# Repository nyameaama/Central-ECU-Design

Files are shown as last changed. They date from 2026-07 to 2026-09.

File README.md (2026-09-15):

# Central ECU

This is the engine-side ECU for the [Converse Engine](https://github.com/nyameaama/Converse-Engine). The engine is packaged as a thruster, so I am keeping everything on this side as small as I can.

Tank isolation, pressurization, regulation, relief, venting, filling, draining, bulk filtration, and service plumbing are all on the tank side. The thruster gets propane, N2O, regulated GN2, 28 V power, and CAN. The Central ECU runs the local firing sequence, drives the six engine valves and spark igniter, reads the engine sensors, and reports back to the vehicle over CAN.

## First design P&ID

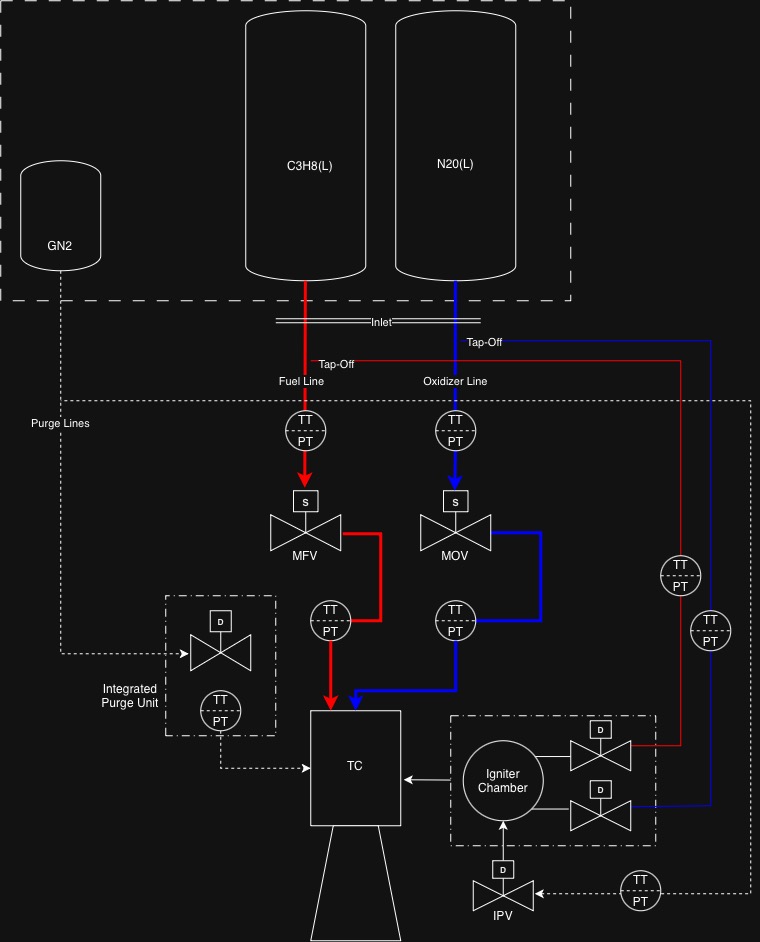
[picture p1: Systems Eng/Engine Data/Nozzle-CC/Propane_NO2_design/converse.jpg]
First design P&ID


This is the first design I am locking down. MFV and MOV are the main engine shutoff valves. IFV and IOV tap off upstream of them so the torch can light before the main valves open. The igniter fuel and oxidizer PT/TT pickups are downstream of IFV and IOV.

The GN2 arriving at the thruster is already regulated. CPV handles the main chamber purge and IPV handles the torch chamber purge. All six fluid valves are normally closed.

## Engine

| Engine | Section view |
| --- | --- |
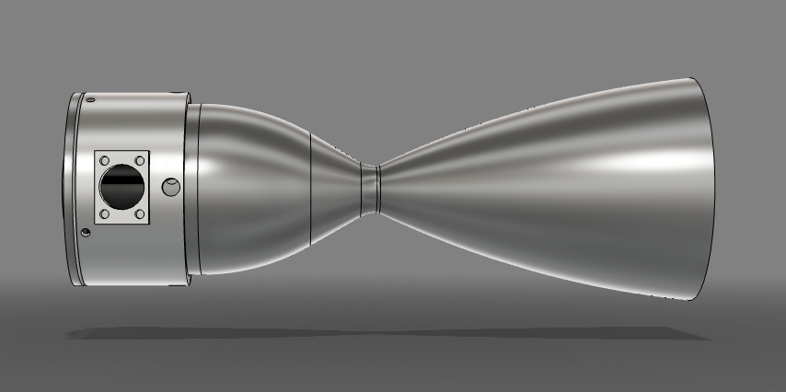
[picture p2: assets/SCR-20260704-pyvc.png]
Converse Engine exterior
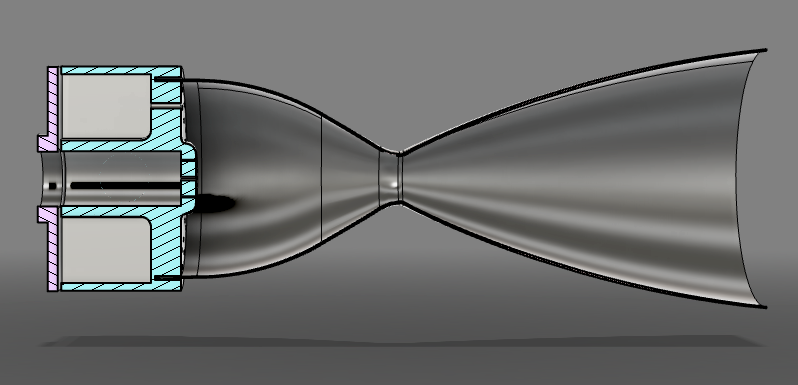
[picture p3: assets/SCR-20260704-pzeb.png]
Converse Engine section
|  |  |

## Current enclosure

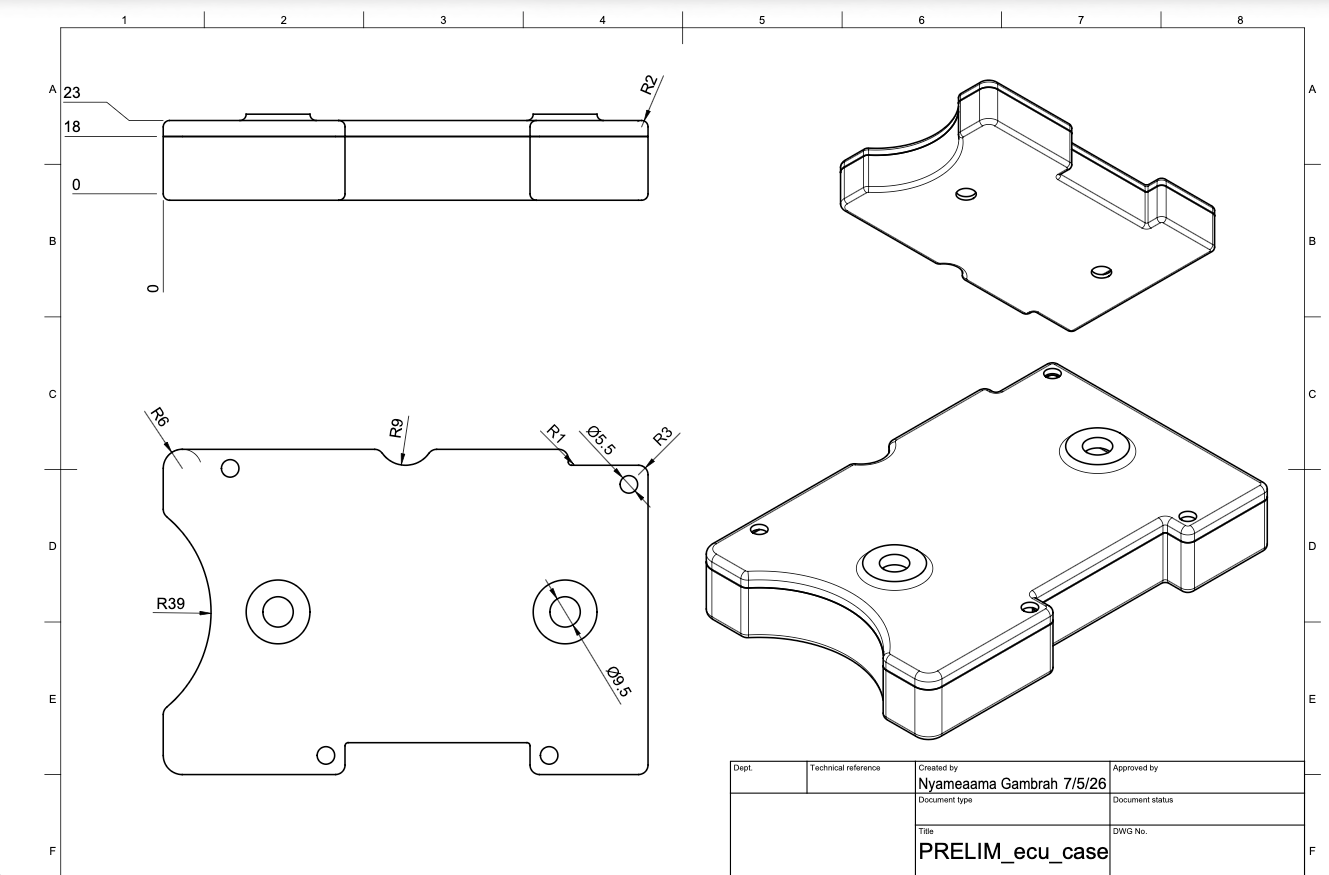
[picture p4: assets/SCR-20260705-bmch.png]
First ECU enclosure


This is the first enclosure pass. I am using it to get a real PCB outline and connector layout.

- 18 mm main body height
- 23 mm max height
- R2 top edge
- R39 PCB keepout
- R6 outer corners with the smaller R9, R7, and R3 transitions from the CAD
- two 9.5 mm engine mounting holes
- 5.5 mm PCB mounting holes
- separate battery clamp with covered terminals and service access
- sealed lid and connector openings

## Power

- 28 V nominal aircraft bus
- regulated 24 V valve rail
- 12 V ignition and sensor rails
- 5 V analog and communications rail
- 3.3 V logic rail
- EnerSys CYCLON `0819-0020`, 12 V 2.5 Ah backup battery

The backup battery only keeps the controller, CAN, and sensor measurements alive. It does not run the valves or igniter. Loss of valve power closes every valve.

## Valves

| Tag | Function | First design part |
| --- | --- | --- |
| MFV | Main propane | Buschjost `2/918-69/0824/.272-GO-1E` |
| MOV | Main N2O | Buschjost `2/918-24/0824/.272-GO-1E` |
| IFV | Torch fuel | Valcor V19800 |
| IOV | Torch oxidizer | Valcor V19800 |
| CPV | Main chamber purge | Parker `20CC04EP7D7B` |
| IPV | Torch chamber purge | Parker `20CC04EP7D7B` |

I have seven identical `TPS26633PWPR` valve channels on the PCB. Six are assigned above and the seventh stays disabled as a spare. `SHDN` is the command for each normally closed valve. Every channel also returns current, fault status, power-good status, and output voltage.

The igniter uses two separate solenoid valves in this build.

## Measurements

I have eleven AST20PT mounting points:

- fuel before and after MFV
- N2O before and after MOV
- igniter fuel after IFV
- igniter oxidizer after IOV
- chamber purge after CPV
- igniter purge after IPV
- remote chamber pressure
- cooling jacket inlet and outlet

The line sensors give pressure and fluid temperature from the same port. Four chamber-wall thermocouples and one injector thermocouple handle the hot structure. ECU and valve-driver temperatures stay on the PCB.

## Firing sequence

The first sequence is:

1. Spark igniter on.
2. IFV and IOV open.
3. Torch pressure comes up.
4. MFV and MOV open.
5. Main chamber pressure comes up.
6. IFV and IOV close.
7. IPV opens and protects the torch during the main burn.
8. MFV and MOV close at shutdown.
9. CPV and IPV handle the post-fire purge.

The largest valve state is the four-valve ignition overlap with MFV, MOV, IFV, and IOV energized together.

## Safety and communications

- arm and safe
- abort and hardware inhibit
- valve power feedback
- igniter enable feedback
- service connector interlock
- CAN FD to the tank and vehicle controllers
- heartbeat and timeout handling
- fault reporting

The tank controller provides the upstream emergency isolation path if an engine valve fails open.

Parts, interfaces, and the power numbers are in [Systems Eng](Systems%20Eng/README.md).

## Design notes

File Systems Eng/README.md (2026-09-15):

# Systems Eng

These are my working numbers for the first thruster build. I am keeping the engine side lean and leaving tank isolation, pressurization, regulation, venting, filling, draining, and bulk filtration on the tank side.

The engine-side hardware is six normally closed valves, eleven AST20PT points, five thermocouples, the spark igniter, and the Central ECU. The PCB has seven valve channels, with six assigned and one spare.

- [First design P&ID](Engine%20Data/Nozzle-CC/Propane_NO2_design/converse.jpg)
- [Parts list](Procurement-BOM.md)
- [Power budget](Power-Budget.md)
- [Sensor interfaces](Sensor-Interface-Control.md)
- [Propellant line sizing](Propellant-Line-Sizing.md)
- [Propane/N2O engine files](Engine%20Data/Nozzle-CC/Propane_NO2_design/)
- [Datasheets](Datasheets/README.md)

The main [README](../README.md) is the short system summary.

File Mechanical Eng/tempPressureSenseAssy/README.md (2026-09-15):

# Temp and Pressure Sensor Assembly

This folder is only for the sensor mounting and cable-routing CAD on the thruster. The tank-side sensors and plumbing are outside this assembly.

My AST20PT locations are:

- fuel before and after MFV
- N2O before and after MOV
- igniter fuel after IFV
- igniter oxidizer after IOV
- chamber purge after CPV
- igniter purge after IPV
- remote chamber pressure pickup
- cooling jacket inlet and outlet

The hot-structure locations are four chamber-wall thermocouples and one injector thermocouple.

The igniter branch sensors sit after their valves. The chamber pressure sensor stays away from the hot wall on a remote pickup. PCB and electrical work stay in the EE project folders.

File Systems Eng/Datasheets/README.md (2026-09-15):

# Datasheets

| Part | File | Note |
| --- | --- | --- |
| TE AST20PT | [TE-AST20PT-Rev-D-2025.pdf](TE-AST20PT-Rev-D-2025.pdf) | Pressure and fluid temperature |
| Omega BLMI | [Omega-BLMI-Mineral-Insulated-Thermocouple.pdf](Omega-BLMI-Mineral-Insulated-Thermocouple.pdf) | Chamber and injector thermocouples |
| Omega PCC-SMP | [Omega-PCC-SMP-PCB-Connector.pdf](Omega-PCC-SMP-PCB-Connector.pdf) | Type K PCB connector |
| Omega SMPW | [Omega-SMPW-Thermocouple-Connector.pdf](Omega-SMPW-Thermocouple-Connector.pdf) | Type K cable connector |
| Phoenix 1681127 | [Phoenix-1681127-M12-Connector.pdf](Phoenix-1681127-M12-Connector.pdf) | AST20PT cable connector |
| MAX31856 | [Analog Devices datasheet](https://www.analog.com/media/en/technical-documentation/data-sheets/max31856.pdf) | Thermocouple interface |
| Buschjost 2/918 R272 | [Buschjost-2-918-R272-100bar.pdf](Buschjost-2-918-R272-100bar.pdf) | Main fuel and oxidizer valves |
| Buschjost 1E sensor | [Buschjost-Inductive-Position-Sensor.pdf](Buschjost-Inductive-Position-Sensor.pdf) | Main-valve position switch |
| Parker G7 | [Parker-G7-Series-Solenoid-Valves.pdf](Parker-G7-Series-Solenoid-Valves.pdf) | CPV and IPV regulated-GN2 purge valves |
| Valcor V19800 | [Valcor-V19800-Fuel-Shutoff-Valve.pdf](Valcor-V19800-Fuel-Shutoff-Valve.pdf) | IFV and IOV torch valves |
| TI TPS2663x | [TI-TPS2663x-eFuse.pdf](TI-TPS2663x-eFuse.pdf) | Per-valve eFuse and high-side switch |
| TDK-Lambda i7A | [TDK-Lambda-i7A-Specification.pdf](TDK-Lambda-i7A-Specification.pdf) | 28 V nominal bus to 24 V valve rail |
| EnerSys CYCLON 0819-0020 | [EnerSys-CYCLON-Selection-Guide.pdf](EnerSys-CYCLON-Selection-Guide.pdf) | Backup battery, 12 V 2x3 monobloc |

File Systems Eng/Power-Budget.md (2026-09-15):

# Power Budget

The vehicle feed is a 28 V nominal aircraft bus. The TDK-Lambda `I7A4W033A033V-003-R` makes the regulated 24 V valve rail. I have seven `TPS26633PWPR` valve channels on the PCB, with six assigned and one disabled spare.

The 24 V converter stays because the selected valve coils are 24 V parts. Raw 28 V is 16.7% above the nameplate voltage of the Buschjost coils.

## Valve loads

| Valve | Assignment | Nominal current | Channel budget current | Coil power |
| --- | --- | ---: | ---: | ---: |
| Buschjost fuel main | MFV | 1.83 A | 1.83 A | 44 W |
| Buschjost oxidizer main | MOV | 2.21 A | 2.21 A | 53 W |
| Valcor V19800, 30 ohm coil | IFV and IOV | not released at 24 V | 1.30 A | 31.2 W each at the budget current |
| Parker G7 | CPV and IPV | 0.42 A | 0.42 A | 10 W each |

MFV and MOV together draw 4.04 A and 97 W. The four-valve ignition overlap adds IFV and IOV and brings the valve rail to 6.64 A and 159.4 W. Normal main operation uses MFV, MOV, and IPV for 4.46 A and 107 W. CPV and IPV together use 0.83 A and 20 W during the full post-fire purge.

Valcor's sheet says 1.3 A at 30 V and 70 F for the 30 ohm coil. The stated current and resistance do not agree, so I carry the published 1.3 A as the worst case on the 24 V channel. The exact hot and cold current comes from the purchased dash number and valve test.

## Valve channels

| Channel | Assignment | `ILIM` resistor | Typical limit |
| ---: | --- | ---: | ---: |
| 1 | MFV | 7.15 kOhm | 2.52 A |
| 2 | MOV | 6.04 kOhm | 2.98 A |
| 3 | IFV | 11.3 kOhm | 1.59 A |
| 4 | IOV | 11.3 kOhm | 1.59 A |
| 5 | CPV | 24.0 kOhm | 0.75 A |
| 6 | IPV | 24.0 kOhm | 0.75 A |
| 7 | Spare | not loaded | disabled |

`SHDN` is the valve command. A 47 kOhm pull-down leaves every channel off while the controller is unpowered or resetting. `MODE` is open for latch-off after an overload. `IMON`, `FLT`, `PGOOD`, and output-voltage sensing return to the AM2634.

The `TPS26633PWPR` has a 31 mOhm typical internal FET. The two main channels dissipate about 0.26 W together including the eFuse operating current. The four-channel ignition state is about 0.49 W using the V19800 channel current. Each output has its own inductive clamp.

## Allowed valve states

| State | Energized valves |
| --- | --- |
| Safe | none |
| Torch light | IFV and IOV |
| Main ignition overlap | MFV, MOV, IFV, and IOV |
| Main run | MFV, MOV, and IPV |
| Post-fire purge | CPV and IPV |

CPV stays out of the ignition and main-run states. IPV stays out of the torch-light state and comes on after IFV and IOV close.

## Electronics loads

| Load | Power |
| --- | ---: |
| 11 AST20PT sensors | 1.32 W |
| AM2634 | 1.46 W |
| Analog supplies and rail monitoring | 5.00 W |
| CAN and service interface | 1.25 W |
| Eight MAX31856 parts | 0.053 W |
| Logic and small-load margin | 0.99 W |
| Two Buschjost position switches | 0.24 W max |
| Critical electronics total | 10.3 W |

The AM2634 number is the 1.460 W result from TI's traction-inverter estimate at 150 C junction. The AM263x supply is `TPS6538600QDCARQ1` plus a `TPS62903-Q1` 3 A core buck.

## Main-bus cases

| State | Input power | Current at 28 V | Equivalent current at 24 V | 25% margin at 24 V |
| --- | ---: | ---: | ---: | ---: |
| Safe, valves off | 12.1 W | 0.43 A | 0.51 A | 0.63 A |
| Post-fire purge, CPV and IPV | 33.2 W | 1.19 A | 1.38 A | 1.73 A |
| Main run, MFV, MOV, and IPV | 124.8 W | 4.46 A | 5.20 A | 6.50 A |
| Ignition overlap, four valves | 179.9 W | 6.43 A | 7.50 A | 9.37 A |

I use 95% efficiency for the 24 V valve conversion and 85% from the 12 V rail through the lower electronics rails. TDK's typical curve is around 97 to 98% near this operating point, so 95% is the number I keep in the budget.

The protected vehicle input is 10 A at 28 V, or 280 W before the igniter load. The released valve and electronics peak is about 180 W during ignition overlap. That leaves about 100 W before margin and about 55 W after applying the 25% system margin.

The i7A input range is 18 to 60 V and it requires the input to stay above the commanded output for regulation. Near a 24 V vehicle-bus minimum, the valve rail tracks below 24 V.

## Igniter

The spark igniter is custom. I have not found an off-the-shelf propane and N2O rocket igniter with a released part number, pressure interface, and input-current waveform for this engine.

Its peak current, pulse width, repetition rate, and maximum firing time are not in the total above yet. The first-design valve side is fixed as separate IFV and IOV solenoids.

## Backup

The controller, CAN, and measurement lines stay alive for 30 minutes after loss of the 28 V bus at ambient temperature down to -15 C. Backup does not power valves or ignition.

The critical electronics use 10.3 W. At 85% conversion efficiency, the battery supplies about 12.1 W or 1.01 A at 12 V. A 50% allowance for discharge rate, cold capacity, aging, state of charge, cutoff, and tolerance leaves 12.75 Wh at the electronics. That gives about 74 minutes by calculation, while my released number stays at 30 minutes.

The backup input is a 3 A path with a battery fuse, service disconnect, reverse-polarity protection, automatic switchover, battery current and voltage measurement, and low-voltage cutoff.

## Sources

- [Buschjost 2/918 R272](https://www.buschjostventile.de/en/products/2-918-08-R-272)
- [Buschjost position sensor](https://www.buschjostventile.de/api/attachments/93eacf07-07ba-4c1d-8806-5cbe40241766.pdf)
- [Parker G7](https://www.parker.com/content/dam/Parker-com/Literature/Fluid-Control-Division/Catalogs/Parker_FCD_Catalog-G7.pdf)
- [Valcor V19800](https://www.valcor.com/valcor-technical-datasheets/valcor_aircraft_V19800.pdf)
- [TI TPS2663](https://www.ti.com/product/TPS2663)
- [TI AM2634](https://www.ti.com/lit/ds/symlink/am2634-q1.pdf)
- [TI AM263x power estimator](https://www.ti.com/lit/an/sprad54/sprad54.pdf)
- [TI AM26x hardware guide](https://www.ti.com/lit/an/sprabjl/sprabjl.pdf)
- [TDK-Lambda i7A](https://product.tdk.com/en/system/files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)
- [EnerSys CYCLON](https://www.enersys.com/en-gb/products/batteries/cyclon/cyclon/)

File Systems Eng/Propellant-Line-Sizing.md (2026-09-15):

# Propellant Line Sizing

The source reports are in [Engine Data/Nozzle-CC/Propane_NO2_design](<Engine%20Data/Nozzle-CC/Propane_NO2_design/>). The [first design P&ID](Engine%20Data/Nozzle-CC/Propane_NO2_design/converse.jpg) is the layout I am carrying into the thruster.

The tank side hands the thruster propane, N2O, and regulated GN2. Tank isolation, pressurization, venting, draining, relief, and bulk filtration stay upstream of the thruster boundary. The engine side only carries the two main paths, the two torch tapoffs, CPV, and IPV.

## Main flow

| Stream | Mass flow | Density in this pass | Volume flow |
| --- | ---: | ---: | ---: |
| Propane | 0.39879 kg/s | 500 kg/m3 | 0.79758 L/s, 12.64 US gpm |
| N2O | 1.75468 kg/s | 750 kg/m3 | 2.33957 L/s, 37.08 US gpm |
| Total | 2.15347 kg/s | - | - |

The full-thrust O/F is 4.400. These mass flows come from `Converse-engine.txt`. The density values are first-pass numbers and stay tied to the actual tank outlet pressure and temperature.

## Bore check

I used:

`Q = mass flow / density`

`ID = sqrt(4 Q / (pi velocity))`

| Mean velocity | Propane ID | N2O ID |
| ---: | ---: | ---: |
| 3 m/s | 18.4 mm, 0.724 in | 31.5 mm, 1.241 in |
| 5 m/s | 14.3 mm, 0.561 in | 24.4 mm, 0.961 in |
| 7 m/s | 12.0 mm, 0.474 in | 20.6 mm, 0.812 in |
| 10 m/s | 10.1 mm, 0.397 in | 17.3 mm, 0.680 in |

The first mechanical interfaces are G1/2 to -8 on fuel and G3/4 to -12 on N2O. The Buschjost valves are local restrictions at DN10 fuel and DN20 oxidizer.

My first valve-drop estimates are:

- MFV: 9.5 psi
- MOV: 16.7 psi

The complete pressure-drop model includes the actual tube IDs, bends, adapters, valve curves, injector requirement, and the cooling-jacket loss if the fuel path uses the jacket. The N2O side also carries margin against flashing through the line and MOV.

## Torch branches

IFV and IOV tap off upstream of MFV and MOV. Their PT/TT points are downstream of the torch valves and upstream of the torch metering points.

The torch flow is a separate low-flow calculation from the main CEA mass flow. The first hardware layout keeps both torch valves independent and uses the downstream pressure and temperature readings with the final metering geometry.

## Purge branches

Regulated GN2 enters at one thruster interface and splits to CPV and IPV.

- CPV feeds the main chamber purge
- IPV feeds the torch chamber purge
- both purge PT/TT points are downstream of their valves
- IPV is on during the main burn after IFV and IOV close
- CPV is a post-fire function

Purge flow is set by the tank-side regulated pressure and the engine-side metering geometry. There are no engine-side propellant vent or manifold dump paths in this design.

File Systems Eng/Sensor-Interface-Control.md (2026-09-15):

# Sensor Interfaces

## AST20PT layout

I am fitting eleven AST20PT sensors for the first thruster build.

| ID | Location | Placement |
| --- | --- | --- |
| FP-IN | Main fuel inlet | Before MFV |
| FP-MAN | Fuel manifold | After MFV |
| OP-IN | Main N2O inlet | Before MOV |
| OP-MAN | N2O manifold | After MOV |
| FP-IGN | Igniter fuel | After IFV and before the torch metering point |
| OP-IGN | Igniter oxidizer | After IOV and before the torch metering point |
| PP-CH | Chamber purge | After CPV |
| PP-IGN | Igniter purge | After IPV |
| PC | Main chamber | Remote pressure pickup with a thermal standoff |
| CJ-IN | Cooling jacket inlet | Jacket inlet port |
| CJ-OUT | Cooling jacket outlet | Jacket outlet port |

The igniter branch sensors are downstream of IFV and IOV. They measure the pressure actually delivered toward the torch instead of repeating the main inlet readings.

Each AST20PT has four electrical connections:

| Signal | ECU connection |
| --- | --- |
| Sensor power | `SENS_12V` |
| Sensor return | `SENS_RTN` |
| Pressure | `P_OUT`, 1 to 5 V |
| Temperature | `T_OUT`, 1 to 5 V |

I carry 10 mA per sensor, or 110 mA and 1.32 W for all eleven. Both outputs have input protection, an RC filter, and scaling into the 3.3 V ADC range. The 1 to 5 V live range leaves room for open- and short-circuit detection.

The sensor-side plug is Phoenix `1681127`. It accepts 18 to 24 AWG wire and 4 to 6 mm cable. My harness baseline is four-core shielded PUR cable with the shield bonded at the ECU end.

The chamber sensor uses the same electrical interface. Its remote tube and restrictor trade temperature protection against pressure-response delay, so the installed response becomes part of the chamber-pressure calibration.

## Thermocouples

The hot-structure probe is Omega `BLMI-XL-K-116U-6-CC`. The cable plug is `SMPW-K-M` and the PCB socket is `PCC-SMP-K-5`.

I am using five channels:

- four chamber-wall points
- one injector point

The PCB keeps eight MAX31856 interfaces, leaving three spare channels. The Type K metal runs straight to the Type K PCB sockets and stays out of the copper AMPSEAL contacts.

Each MAX31856 uses 3.3 V, SPI clock and data, one chip select, and the datasheet input filter. `DRDY` and `FAULT` return to the controller where pins are available.

## Main sensor connectors

Two 35-way AMPSEAL headers give 70 cavities.

| Use | Cavities |
| --- | ---: |
| AST20PT pressure outputs | 11 |
| AST20PT temperature outputs | 11 |
| Sensor power feeds | 2 |
| Sensor returns | 2 |
| Spare | 44 |
| Total | 70 |

The two harness branches split sensor power and return. The thermocouples use their own Type K connectors.

## Main-valve position feedback

The Buschjost `1E` option is a three-wire PNP normally open inductive sensor. It runs from 10 to 30 VDC, draws less than 10 mA, and can source 100 mA.

Both position switches run from `SENS_12V`, which keeps closed-valve indication alive on backup power. A protected divider and Schmitt input bring each signal into the AM2634. My selected valve configuration reports the closed position.

## PCB notes

- AST20PT supply range is 10 to 28 V
- AST20PT sample rate is 400 Hz maximum
- sensor ground joins valve return at the power entry point
- the analog filter corner follows the selected sample rate
- ECU board temperature and valve-driver temperature are local PCB measurements

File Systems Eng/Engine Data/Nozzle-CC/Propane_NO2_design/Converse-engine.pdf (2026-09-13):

## Engine name: Converse

Mon Nov 29 20:46:48 2021

Propellant Specification
Component Temperature (K) Mass fraction Mole fraction
C3H8(L) | 231.08 | 0.19 | 0.18
N2O(L),298.15K | 298.15 | 0.81 | 0.82
| Total | 1.00 | 1.00
Exploded propellant formula:N1.630 O0.815 C0.555 H1.479
| O/F = 4.400
O/F⁰ = 9.981 (stoichiometric) αox = 0.441 (oxidizer excess coefficient)

Table 1. Thermodynamic properties

Parameter | Injector | Nozzle inlet | Nozzle throat | Nozzle exit | Unit
Pressure | 3.4474 | 3.4474 | 1.8973 | 0.0117 | MPa
Temperature | 2400.6726 | 2400.6726 | 2116.4505 | 823.2841 | K
Enthalpy | 666.6951 | 666.6951 | 129.7272 | -2476.5175 | kJ/kg
Entropy | 10.9970 | 10.9970 | 10.9970 | 10.9970 | kJ/(kg·K)
Internal energy | -290.2740 | -290.2740 | -713.5100 | -2790.7130 | kJ/kg
Specific heat (p=const) | 1.9405 | 1.9405 | 1.8640 | 10.3246 | kJ/(kg·K)
Specific heat (V=const) | 1.5351 | 1.5351 | 1.4634 | 8.7935 | kJ/(kg·K)
Gamma | 1.2641 | 1.2641 | 1.2738 | 1.1741
Isentropic exponent | 1.2636 | 1.2636 | 1.2736 | 1.1169
Gas constant | 0.3986 | 0.3986 | 0.3984 | 0.3816 | kJ/(kg·K)
Molecular weight (M) | 20.8579 | 20.8579 | 20.8686 | 21.7864
Molecular weight (MW) | 0.02086 | 0.02086 | 0.02087 | 0.02124
Density | 3.6024 | 3.6024 | 2.2500 | 0.0372 | kg/m³
Sonic velocity | 1099.6349 | 1099.6349 | 1036.3089 | 592.3949 | m/s
Velocity | 0.0000 | 0.0000 | 1036.3089 | 2507.2745 | m/s
Mach number | 0.0000 | 0.0000 | 1.0000 | 4.2324
Area ratio | infinity | infinity | 1.0000 | 25.0000
Mass flux | 0.0000 | 0.0000 | 2331.7360 | 93.2322 | kg/(m²·s)
Mass flux (relative) | 0.000e-04 | 0.000e-04 | | | kg/(N·s)
Viscosity | 7.56e-05 | 7.56e-05 | 6.929e-05 | 3.673e-05 | kg/(m·s)
Conductivity, frozen | 0.2451 | 0.2451 | 0.2198 | 0.1049 | W/(m·K)
Specific heat (p=const), frozen | 1.852 | 1.852 | 1.822 | 1.581 | kJ/(kg·K)
Prandtl number, frozen | 0.5711 | 0.5711 | 0.5744 | 0.5533
Conductivity, effective | 0.2826 | 0.2826 | 0.2332 | nan | W/(m·K)
Specific heat (p=const), effective | 1.941 | 1.941 | 1.864 | 1.581 | kJ/(kg·K)
Prandtl number, effective | 0.5191 | 0.5191 | 0.5539 | nan

Table 2. Fractions of the combustion products

Species | Injector Injector Nozzle inlet Nozzle inlet mass | mole
mass | mole fractions | fractions fractions
fractions

Nozzle Nozzle Nozzle exit Nozzle exit throat throat mass mole
mass | mole | fractions | fractions
| | | | | fractions | fractions
C(gr) | | | | | | | 0.0141885 0.0250908
CH4 | 0.0000002 | 0.0000002 | 0.0000002 | 0.0000002 | 0.0000002 | 0.0000003 | 0.0066388 0.0087896
CO | 0.3288592 | 0.2448866 | 0.3288592 | 0.2448866 | 0.3256783 | 0.2426427 | 0.1754557 0.1330459
CO2 | 0.0377299 | 0.0178817 | 0.0377299 | 0.0178817 | 0.0427448 | 0.0202689 | 0.2085925 0.1006702
1
Species | Injector mass fractions
Injector Nozzle inlet Nozzle inlet | Nozzle
| | | | | throat mass fractions | | Nozzle Nozzle exit Nozzle exit
| | mole fractions | mass fractions | mole fractions | | throat mole fractions
mass | mole
fractions | fractions
COOH | 0.0000003 | 0.0000001 | 0.0000003 | 0.0000001
H | 0.0000650 | 0.0013455 | 0.0000650 | 0.0013455 | 0.0000190 | 0.0003941
H2 | 0.0236045 | 0.2442308 | 0.0236045 | 0.2442308 | 0.0238767 | 0.2471740 | 0.0266082 0.2803491
H2O | 0.0910036 | 0.1053628 | 0.0910036 | 0.1053628 | 0.0890350 | 0.1031366 | 0.0498966 0.0588273
HCHO,formaldehy | 0.0000012 | 0.0000008 | 0.0000012 | 0.0000008 | 0.0000007 | 0.0000005
HCN | 0.0000148 | 0.0000114 | 0.0000148 | 0.0000114 | 0.0000085 | 0.0000066
HCO | 0.0000026 | 0.0000019 | 0.0000026 | 0.0000019 | 0.0000007 | 0.0000005
HCOOH | 0.0000007 | 0.0000003 | 0.0000007 | 0.0000003 | 0.0000004 | 0.0000002
HNC | 0.0000014 | 0.0000011 | 0.0000014 | 0.0000011 | 0.0000005 | 0.0000004
HNCO | 0.0000029 | 0.0000014 | 0.0000029 | 0.0000014 | 0.0000016 | 0.0000008
N2 | 0.5185805 | 0.3861180 | 0.5185805 | 0.3861180 | 0.5185934 | 0.3863262 | 0.5185982 0.3932003
NH2 | 0.0000005 | 0.0000007 | 0.0000005 | 0.0000007 | 0.0000001 | 0.0000001
NH3 | 0.0000246 | 0.0000302 | 0.0000246 | 0.0000302 | 0.0000199 | 0.0000244 | 0.0000213 0.0000266
NO | 0.0000111 | 0.0000077 | 0.0000111 | 0.0000077 | 0.0000014 | 0.0000010
O | 0.0000003 | 0.0000004 | 0.0000003 | 0.0000004
OH | 0.0000963 | 0.0001181 | 0.0000963 | 0.0001181 | 0.0000184 | 0.0000226

Table 3. Theoretical (ideal) performance
Parameter | Sea level | Sea level (flow sep.) | Optimum expansion | Vacuum | Unit
Characteristic velocity | | | 1478.46 | | m/s
Effective exhaust velocity | 1545.78 | 1768.87 | 2507.27 | 2632.59 | m/s
Specific impulse (by mass) | 1545.78 | 1768.87 | 2507.27 | 2632.59 | N·s/kg
Specific impulse (by weight) | 157.63 | 180.37 | 255.67 | 268.45 | s
Thrust coefficient | 1.0455

Table 4. Estimated delivered performance

1.1964 | 1.6959 | 1.7806
Parameter | Sea level | Sea level (flow sep.) | Optimum expansion | Vacuum | Unit
Characteristic velocity | | | 1438.85 | | m/s
Effective exhaust velocity | 1417.46 | 1643.14 | 2378.95 | 2504.26 | m/s
Specific impulse (by mass) | 1417.46 | 1643.14 | 2378.95 | 2504.26 | N·s/kg

Specific impulse (by weight) | 144.54 | 167.55 | 242.59 | 255.36

s
Thrust coefficient | 0.9851 | 1.1420 | 1.6534 | 1.7405
Ambient condition for optimum expansion: H=15.23 km, p=0.115 atm
2

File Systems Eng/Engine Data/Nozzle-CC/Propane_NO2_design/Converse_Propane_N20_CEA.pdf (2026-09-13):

NASA-GLENN CHEMICAL EQUILIBRIUM PROGRAM CEA2, FEBRUARY 5, 2004 BY BONNIE MCBRIDE AND SANFORD GORDON REFS: NASA RP-1311, PART I, 1994 AND NASA RP-1311, PART II, 1996

*******************************************************************************

### CEA analysis performed on Tue 14-Dec-2021 15:02:54

# Problem Type: "Rocket" (Infinite Area Combustor)

prob case=Converse_______2705 ro equilibrium

# Pressure (1 value):

p,psia= 750
# Chamber/Exit Pressure Ratio (1 value): pi/p= 51.02

# Oxidizer/Fuel Wt. ratio (1 value):

o/f= 4.4

# You selected the following fuels and oxidizers: reac

fuel C3H8(L) | wt%=100.0000
oxid N2O | wt%=100.0000

# You selected these options for output:

# short version of output

output short
# Proportions of any products will be expressed as Mass Fractions. output massf

# Heat will be expressed as siunits

output siunits

# Input prepared by this script:/var/www/sites/cearun.grc.nasa.gov/cgi-bin/CEARU N/prepareInputFile.cgi

### IMPORTANT: The following line is the end of your CEA input file!

end

THEORETICAL ROCKET PERFORMANCE ASSUMING EQUILIBRIUM

COMPOSITION DURING EXPANSION FROM INFINITE AREA COMBUSTOR

Pin = 750.0 PSIA
CASE = Converse_______
REACTANT | WT FRACTION | ENERGY | TEMP
(SEE NOTE) | KJ/KG-MOL | K
FUEL | C3H8(L) | 1.0000000 | -128228.000 | 231.076
OXIDANT | N2O | 1.0000000 | 0.000 | 0.000
O/F= | 4.40000 | %FUEL= 18.518519 | R,EQ.RATIO= 2.268459 | PHI,EQ.RATIO= 2.268459
CHAMBER | THROAT | EXIT
Pinf/P | 1.0000 | 1.8248 | 51.020
P, BAR | 51.710 | 28.338 | 1.0135
T, K | 1751.69 | 1532.82 | 906.28
RHO, KG/CU M | 7.4122 0 4.6426 0 2.9816-1
H, KJ/KG | -538.51 | -931.32 -2414.33
U, KJ/KG | -1236.15 -1541.71 -2754.26
G, KJ/KG | -18495.7 -16644.7 -11704.9
S, KJ/(KG)(K) | 10.2513 | 10.2513 | 10.2513
M, (1/n) | 20.877 | 20.880 | 22.167
MW, MOL WT | 20.877 | 20.880 | 21.655
(dLV/dLP)t | -1.00030 -1.00056 -1.05903
(dLV/dLT)p | 1.0018 | 1.0045 | 2.0623
Cp, KJ/(KG)(K) | 1.8066 | 1.7967 | 9.2320
GAMMAs | 1.2836 | 1.2871 | 1.1284
SON VEL,M/SEC | 946.3 | 886.4 | 619.3
MACH NUMBER | 0.000 | 1.000 | 3.127

PERFORMANCE PARAMETERS

Ae/At | 1.0000 | 7.1255
CSTAR, M/SEC | 1256.6 | 1256.6
CF | 0.7054 | 1.5414
Ivac, M/SEC | 1575.0 | 2112.4
Isp, M/SEC | 886.4 | 1936.9

MASS FRACTIONS

CH4 | 0.00003 | 0.00008 | 0.01386
*CO | 0.31866 | 0.31151 | 0.17791
*CO2 | 0.05367 | 0.06478 | 0.18999
HCN | 0.00003 | 0.00002 | 0.00000
*H2 | 0.02437 | 0.02486 | 0.02326
H2O | 0.08463 | 0.08013 | 0.06355
NH3 | 0.00011 | 0.00011 | 0.00007
*N2 | 0.51851 | 0.51852 | 0.51855
C(gr) | 0.00000 | 0.00000 | 0.01280

* THERMODYNAMIC PROPERTIES FITTED TO 20000.K

NOTE. WEIGHT FRACTION OF FUEL IN TOTAL FUELS AND OF OXIDANT IN TOTAL OXIDANTS

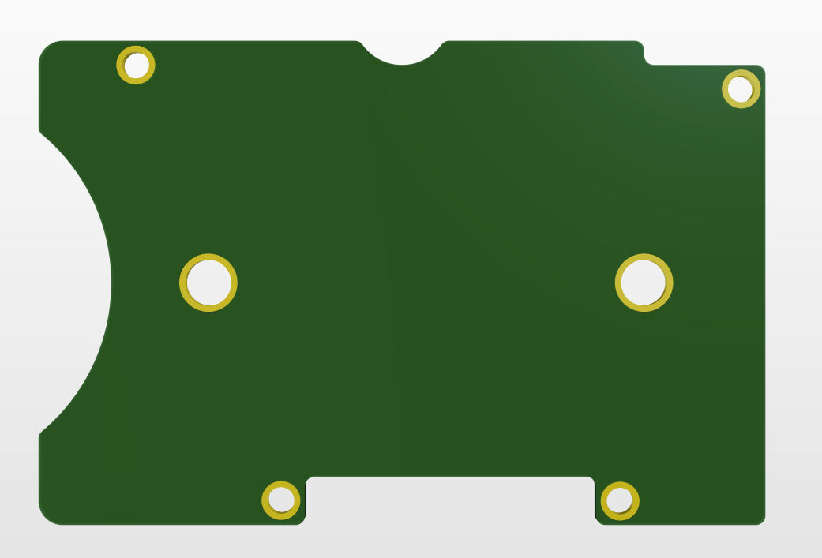
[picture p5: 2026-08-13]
assets/SCR-20260705-bvih.png

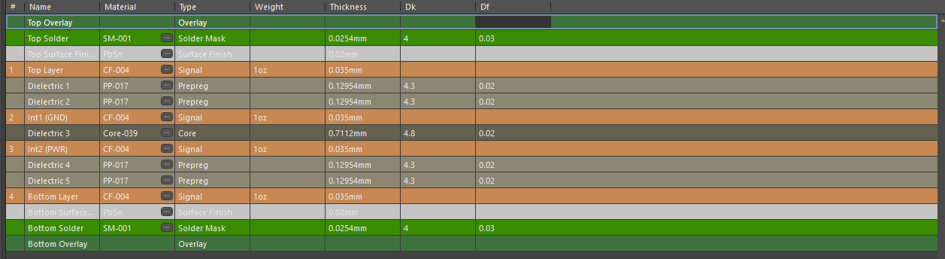
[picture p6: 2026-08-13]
assets/SCR-20260705-bvmq.png

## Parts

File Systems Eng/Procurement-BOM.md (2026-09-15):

# Parts List

This is the first-build list for the six-valve thruster. My last general stock check was 2026-08-01. I checked the TPS26633, i7A, and Parker G7 again on 2026-08-28.

## Sensors

| Buy | Fitted | Part | Where I am using it |
| ---: | ---: | --- | --- |
| 12 | 11 | TE `AST20PT4A01500P3Y1H000` | Main lines, igniter branches, both purge branches, remote chamber pickup, and cooling jacket |
| 12 | 11 | Phoenix `1681127` | Field-wireable M12 plug for each AST20PT |
| 5 | 5 | Omega `BLMI-XL-K-116U-6-CC` | Four chamber-wall points and one injector point |
| 5 | 5 | Omega `SMPW-K-M` | Type K cable plug |
| 1 pack | 5 | Omega `PCC-SMP-K-5` | Type K PCB sockets |
| 8 | 8 | Analog Devices `MAX31856MUD+T` | Five thermocouple channels and three spares |

The eleven AST20PT points are:

1. Fuel before MFV
2. Fuel after MFV
3. N2O before MOV
4. N2O after MOV
5. Igniter fuel after IFV
6. Igniter oxidizer after IOV
7. Chamber purge after CPV
8. Igniter purge after IPV
9. Remote chamber pressure
10. Cooling jacket inlet
11. Cooling jacket outlet

The selected AST20PT is 0 to 1500 psig with separate 1 to 5 V pressure and temperature outputs, an M12 connector, and a 1/4 inch MNPT process port. I am carrying one spare sensor and one spare M12 plug.

## ECU connectors

| Qty | Part | Use |
| ---: | --- | --- |
| 1 | TE `776231-1` | Black 35-way AMPSEAL PCB header |
| 1 | TE `776231-2` | Natural 35-way AMPSEAL PCB header |
| 1 | TE `776164-1` | Black mating plug |
| 1 | TE `776164-2` | Natural mating plug |
| 70 plus spares | TE `770520-3` | Gold socket contacts, 16 to 20 AWG |
| as needed | TE `770678-1` | Cavity plugs |

The two headers carry 22 AST20PT signal wires, two sensor-power feeds, two returns, and 44 spare cavities. The Type K connections stay separate from the AMPSEAL connectors.

## Valves

| Qty | Part | Assignment | What I am carrying |
| ---: | --- | --- | --- |
| 1 | Buschjost `2/918-69/0824/.272-GO-1E`, 24 VDC | MFV | NC direct coaxial valve, G1/2, DN10, Kv 2.5, 44 W |
| 1 | Buschjost `2/918-24/0824/.272-GO-1E`, 24 VDC | MOV | NC direct coaxial valve, G3/4, DN20, Kv 6.8, 53 W |
| 2 | Parker `20CC04EP7D7B`, 24 VDC | CPV and IPV | NC direct-acting G7 valve, 1/4 NPT, Cv 0.05, 10 W |
| 2 | Parker `ELECE5` | CPV and IPV | Six-foot DIN cord set |
| 2 | Valcor `V19800`, NC, 0.085 inch ESEO, 30 ohm continuous coil, top `MS3102A-10SL-4P` receptacle | IFV and IOV | First-design torch valves |
| 2 | Amphenol `MS3106A10SL-4S` | IFV and IOV | Cable plug for the Valcor receptacle |

The engine-side valve count stops at these six.

The main engine model calls for 0.39879 kg/s propane and 1.75468 kg/s N2O. My first density pass uses 0.50 kg/L propane and 0.75 kg/L N2O. That works out to 12.6 gpm fuel and 37.1 gpm oxidizer.

| | Fuel | Oxidizer |
| --- | ---: | ---: |
| Port and bore | G1/2, DN10 | G3/4, DN20 |
| Kv | 2.5 m3/h | 6.8 m3/h |
| Coil | 44 W | 53 W |
| Current at 24 V | 1.83 A | 2.21 A |
| Catalog switching time at 6 bar gas | 50 ms on, 80 ms off | 110 ms on, 100 ms off |
| First valve-drop estimate | 9.5 psi | 16.7 psi |

Both Buschjost configurations are normally closed, direct-electric 316 Ti stainless valves with PTFE/FKM seals. They are listed for 0 to 100 bar and continuous coil duty. `GO` is the cleaned version and `1E` adds one closed-position inductive sensor. The fuel side uses G1/2 to -8 and the oxidizer side uses G3/4 to -12.

The Buschjost resistance table lists the wetted materials as compatible with LPG and N2O. I still have the 100 bar feed limit, -10 C temperature floor, reverse-pressure limit, and actual `GO` cleaning certificate tied to the purchased configuration. The published switching times are gas tests, so my liquid timing comes from the assembled valve test.

The Parker G7 is only on regulated GN2. It is listed for zero to 2200 psi differential with air or inert gas, has a 3/64 inch orifice, and uses a 10 W coil. CPV feeds the main chamber purge and IPV feeds the torch chamber purge.

The V19800 setup is the 30 ohm continuous coil. Valcor's sheet also states 1.3 A at 30 V and 70 F, which does not agree with the listed 30 ohm resistance. I use the published 1.3 A as the per-channel worst case. The exact 24 V hot and cold current stays tied to the factory dash number and my valve bench data.

## ECU power parts

| Buy | Fitted | Part | Use |
| ---: | ---: | --- | --- |
| 1 | 1 | TDK-Lambda `I7A4W033A033V-003-R` | 28 V nominal bus to regulated 24 V valve rail |
| 8 | 7 | TI `TPS26633PWPR` | Six assigned valve channels and one disabled spare |
| 1 | 1 | TI `TPS6538600QDCARQ1` | AM2634 sequencing, watchdog, and supply supervision |
| 1 | 1 | TI `TPS62903-Q1` | 1.2 V AM2634 core supply |

The Buschjost coils stay on the regulated 24 V rail. I am not running the 24 V coils straight from the 28 V aircraft bus.

Every valve channel uses `SHDN` as the command and has a 47 kOhm pull-down. `IMON`, `FLT`, `PGOOD`, and output-voltage sensing return to the controller. The first current-limit values are:

| Valve channel | `ILIM` resistor | Typical limit |
| --- | ---: | ---: |
| MFV | 7.15 kOhm | 2.52 A |
| MOV | 6.04 kOhm | 2.98 A |
| CPV and IPV | 24.0 kOhm | 0.75 A |
| IFV and IOV | 11.3 kOhm | 1.59 A |

Each output has its own inductive clamp near the harness connector. The clamp voltage and release timing stay tied to the valve bench data because the coil inductance is not published.

## Backup battery

| Qty | Part | Use |
| ---: | --- | --- |
| 1 | EnerSys CYCLON `0819-0020` | 12 V, 2.5 Ah AGM backup battery |
| 1 | Power-Sonic `PSC-12500ACX` | Ground-service AGM charger |

The battery only carries the controller, CAN, and measurement electronics. It does not carry valves or ignition.

The battery is 113.8 x 89.4 x 70.4 mm, weighs 1.04 kg, and uses 0.187 inch Faston terminals. My enclosure has a separate clamp, covered terminals, a positive-terminal fuse, reverse-polarity protection, current measurement, automatic switchover, and low-voltage cutoff.

## Part status

- AST20PT is an active TE family. The selected configuration still goes through a TE or LADD quote.
- The Phoenix M12 plug, Omega connectors, MAX31856, TPS26633, TI power parts, i7A, and CYCLON battery are active parts.
- The two Buschjost main valves are made to order and have public STEP models.
- The Parker G7 is the released GN2 purge valve and has manufacturer CAD.
- The Valcor V19800 family is the released IFV/IOV choice for this pass. The factory dash number and fluid approval come back with the quote.

## Links

- [AST20PT](https://www.te.com/en/product-CAT-PTT0038.html)
- [Phoenix 1681127](https://www.digikey.com/en/products/detail/phoenix-contact/1681127/2510450)
- [Omega BLMI probe](https://blackhawksupply.com/products/omega-blmi-xl-k-116u-6-cc)
- [Omega SMPW-K-M](https://www.digikey.com/en/products/detail/omega/SMPW-K-M/25638955)
- [Omega PCC-SMP-K-5](https://www.digikey.com/en/products/detail/omega/PCC-SMP-K-5/25639954)
- [MAX31856](https://www.analog.com/en/products/max31856.html)
- [TE 776231-1](https://www.te.com/en/product-776231-1.html)
- [TE 776164-1](https://www.te.com/en/product-776164-1.html)
- [Buschjost fuel valve](https://www.buschjostventile.de/en/products/2-918-08-R-272/details/2-918-69-0824-R272-GO-1E)
- [Buschjost oxidizer valve](https://www.buschjostventile.de/en/products/2-918-08-R-272/details/2-918-24-0824-R272-GO-1E)
- [Buschjost material table](https://www.buschjostventile.de/api/pdf/resistance-table?locale=en)
- [Buschjost position sensor](https://www.buschjostventile.de/api/attachments/93eacf07-07ba-4c1d-8806-5cbe40241766.pdf)
- [Parker G7 catalog](https://www.parker.com/content/dam/Parker-com/Literature/Fluid-Control-Division/Catalogs/Parker_FCD_Catalog-G7.pdf)
- [Parker G7 CAD](https://parker-embedded.partcommunity.com/3d-cad-models/sso/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)
- [Valcor V19800](https://www.valcor.com/valcor-technical-datasheets/2-way-direct-acting-shut-off-solenoid-valve-V19800.pdf)
- [Amphenol valve plug](https://www.digikey.com/en/products/detail/amphenol-industrial-operations/MS3106A10SL-4S/378636)
- [EnerSys CYCLON](https://www.enersys.com/en-gb/products/batteries/cyclon/cyclon/)
- [TDK-Lambda i7A](https://product.tdk.com/en/search/power/switching-power/dc-dc-converter/info?part_no=I7A4W033A033V-003-R)
- [TI TPS2663](https://www.ti.com/product/TPS2663)
- [TI TPS653860-Q1](https://www.ti.com/product/TPS653860-Q1)
- [TI TPS62903-Q1](https://www.ti.com/product/TPS62903-Q1)

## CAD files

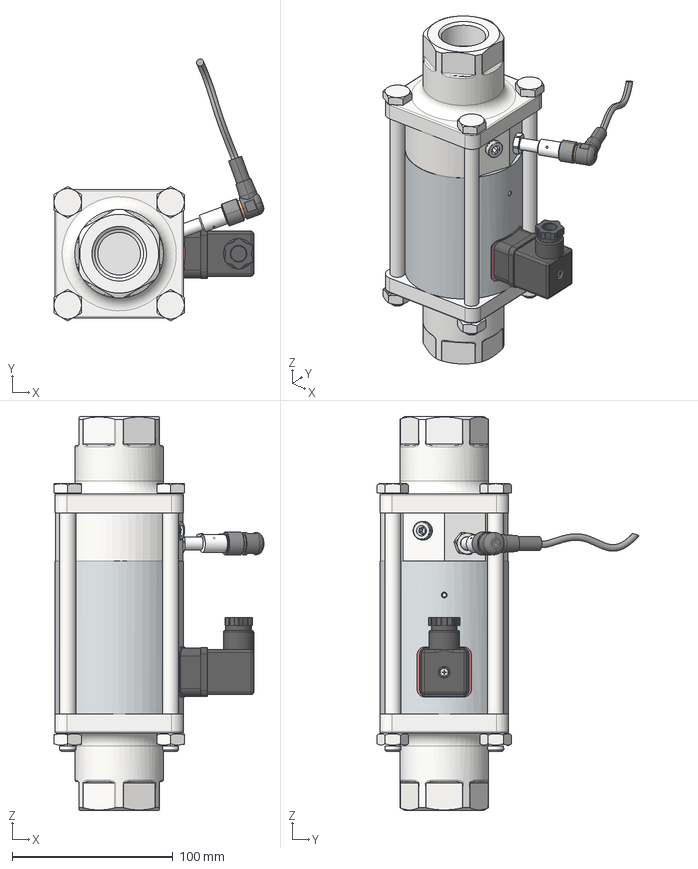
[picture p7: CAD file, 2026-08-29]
Mechanical Eng/Component CAD/Buschjost-2-918/Buschjost-2-918-DN20-G3-4-R272-GO-1E.step
130.5 x 162.9 x 245.0 mm

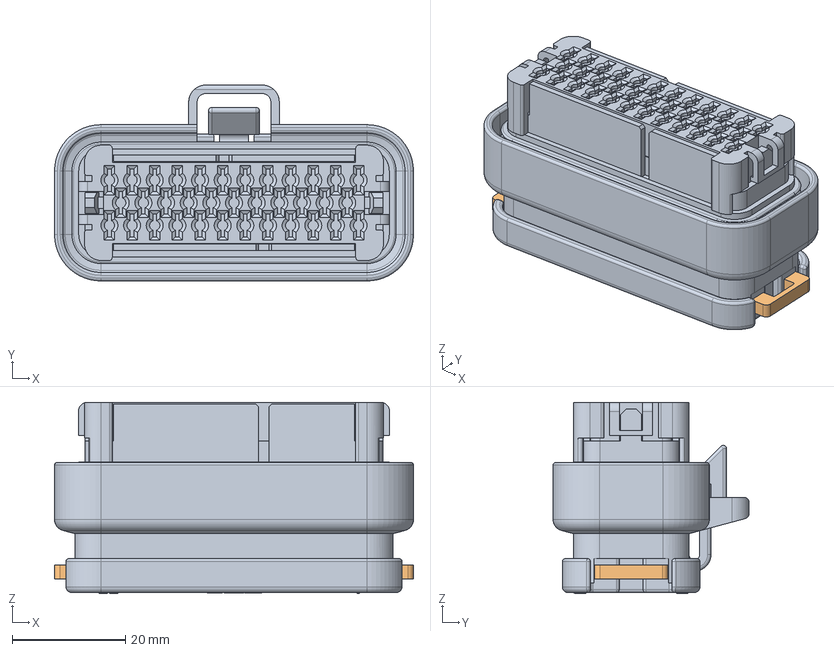
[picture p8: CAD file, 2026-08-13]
Mechanical Eng/Component CAD/TE-AMPSEAL/c-776164-2-f-3d.stp
63.4 x 34.6 x 33.8 mm

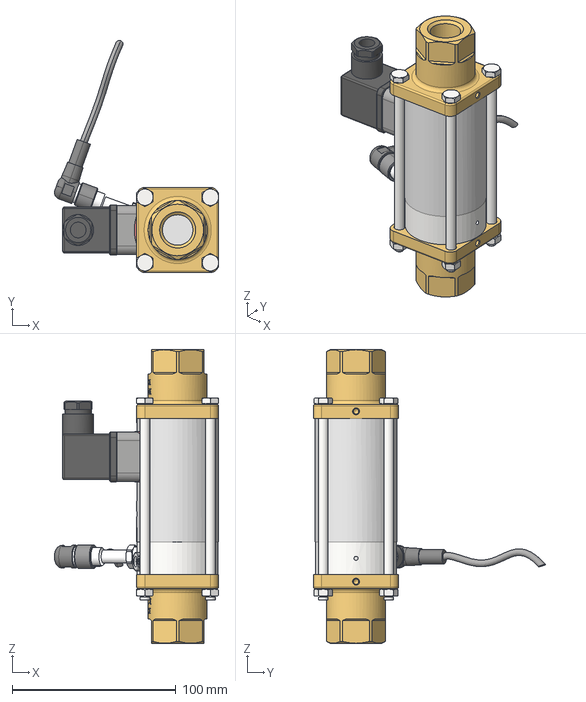
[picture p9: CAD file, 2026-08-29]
Mechanical Eng/Component CAD/Buschjost-2-918/Buschjost-2-918-DN10-G1-2-R272-GO-1E.step
100.3 x 141.7 x 179.5 mm

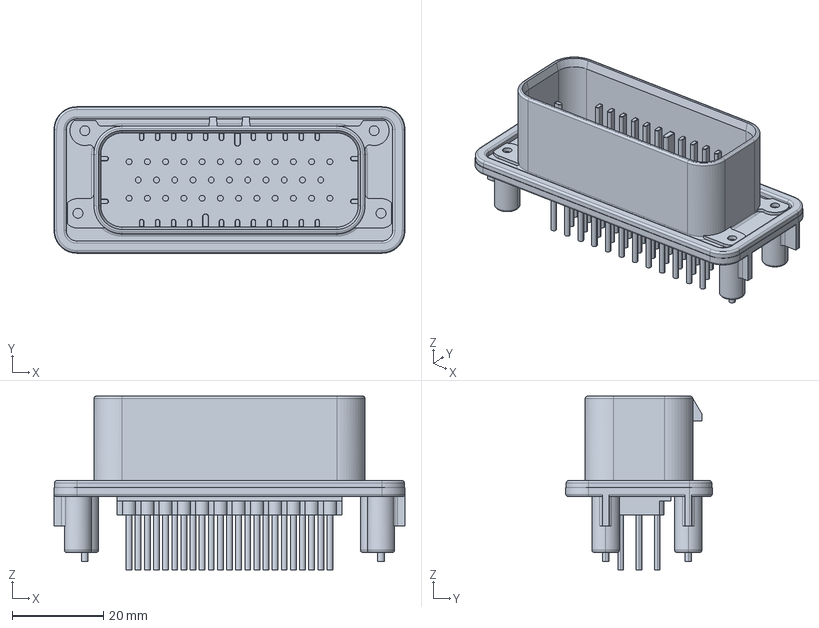
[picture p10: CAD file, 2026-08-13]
Mechanical Eng/Component CAD/TE-AMPSEAL/c-776231-2-d-3d.stp
76.9 x 32.1 x 38.0 mm

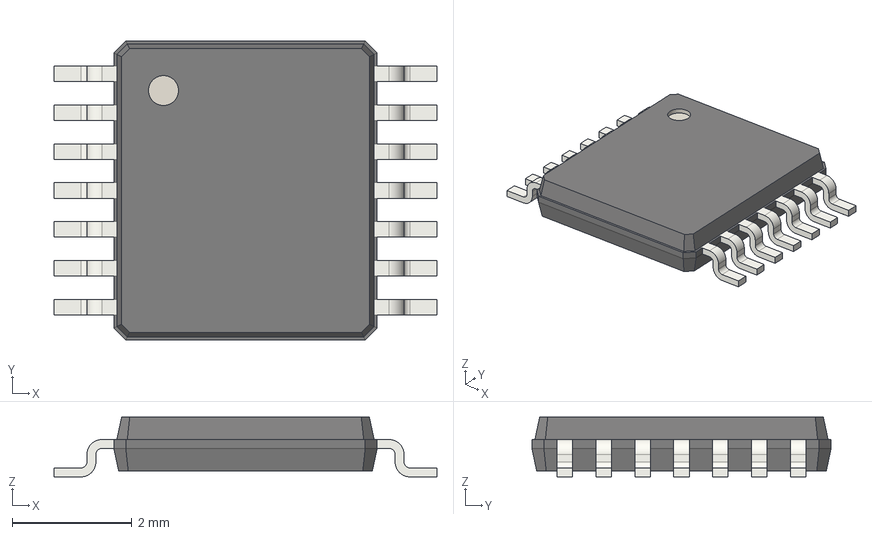
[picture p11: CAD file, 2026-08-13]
Mechanical Eng/Component CAD/PCB/MAX31856_TSSOP-14.step
6.40 x 5.00 x 1 mm

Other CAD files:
Mechanical Eng/Component CAD/TE-AMPSEAL/c-776231-1-d-3d.stp
Mechanical Eng/Component CAD/TE-AMPSEAL/c-776164-1-f-3d.stp
Mechanical Eng/Component CAD/PurgeValve/20CC04EP7D7B.iam
Mechanical Eng/Component CAD/PurgeValve/20CC04EP7D7B_PART1.ipt
Mechanical Eng/Component CAD/PurgeValve/20CC04EP7D7B_PART10.ipt
Mechanical Eng/Component CAD/PurgeValve/20CC04EP7D7B_PART11.ipt
Mechanical Eng/Component CAD/PurgeValve/20CC04EP7D7B_PART12.ipt
Mechanical Eng/Component CAD/PurgeValve/20CC04EP7D7B_PART13.ipt
Mechanical Eng/Component CAD/PurgeValve/20CC04EP7D7B_PART14.ipt
Mechanical Eng/Component CAD/PurgeValve/20CC04EP7D7B_PART15.ipt
Mechanical Eng/Component CAD/PurgeValve/20CC04EP7D7B_PART2.ipt
Mechanical Eng/Component CAD/PurgeValve/20CC04EP7D7B_PART3.ipt
Mechanical Eng/Component CAD/PurgeValve/20CC04EP7D7B_PART4.ipt
Mechanical Eng/Component CAD/PurgeValve/20CC04EP7D7B_PART5.ipt
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

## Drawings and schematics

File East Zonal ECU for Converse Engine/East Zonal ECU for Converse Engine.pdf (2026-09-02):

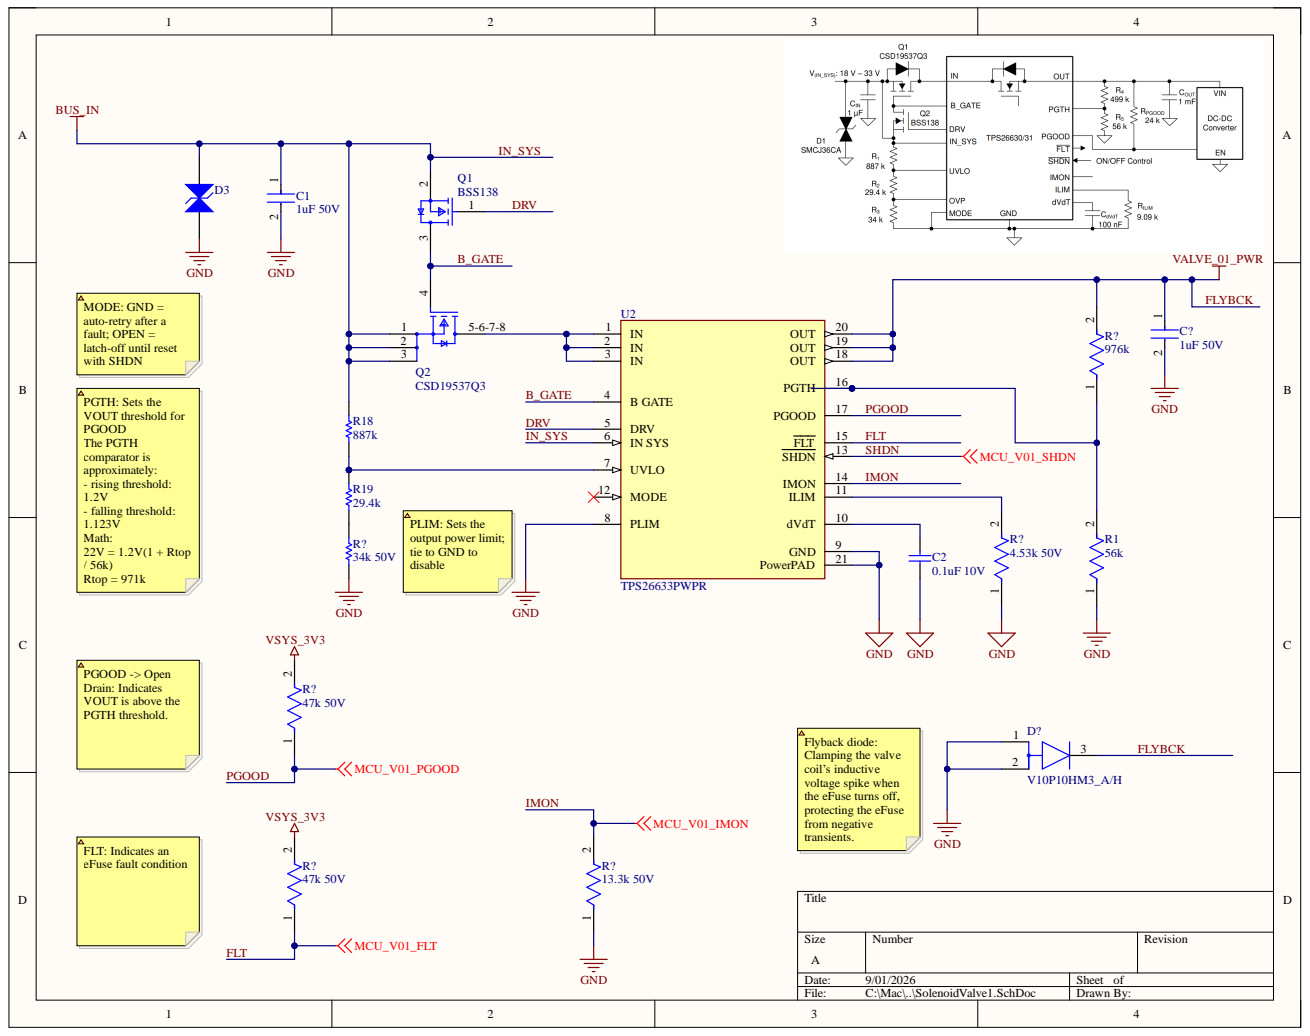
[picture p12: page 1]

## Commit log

2026-07-05 init design
    [AM2634_5_EPWM.SchDoc, AM2634_6.SchDoc, AM263_1.SchDoc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]
2026-08-02 sys eng stuff add
    [MAX31856_TSSOP-14.step, c-776164-1-f-3d.stp, c-776164-2-f-3d.stp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]
2026-08-13 push updates
    [ECU.PcbDoc, LM70880QRRXRQ1.PcbLib, LM70880QRRXRQ1.SchLib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]
2026-08-13 ADD CAN SCH
    [CAN.SchDoc]
2026-08-29 sys update
    [Buschjost-2-918-DN10-G1-2-R272-GO-1E.step, Buschjost-2-918-DN20-G3-4-R272-GO-1E.step]
2026-08-29 add purge valve cad
    [20CC04EP7D7B.iam, 20CC04EP7D7B_PART1.ipt, 20CC04EP7D7B_PART10.ipt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]
2026-09-02 valve schematic additions
    [AM263x_LP.SCHLIB, ECU.PcbDoc, East Zonal ECU for Converse Engine.PrjPcb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]
2026-09-04 mcu pins config initial
    [AM2634_5_EPWM.SchDoc, CAN.SchDoc, SolenoidValve1.SchDoc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]

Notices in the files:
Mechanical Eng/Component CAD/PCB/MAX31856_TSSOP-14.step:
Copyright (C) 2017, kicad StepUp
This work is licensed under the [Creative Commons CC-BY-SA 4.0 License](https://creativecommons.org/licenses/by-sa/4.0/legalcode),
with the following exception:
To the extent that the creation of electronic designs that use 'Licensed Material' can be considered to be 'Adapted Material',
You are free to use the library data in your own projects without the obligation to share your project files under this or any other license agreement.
